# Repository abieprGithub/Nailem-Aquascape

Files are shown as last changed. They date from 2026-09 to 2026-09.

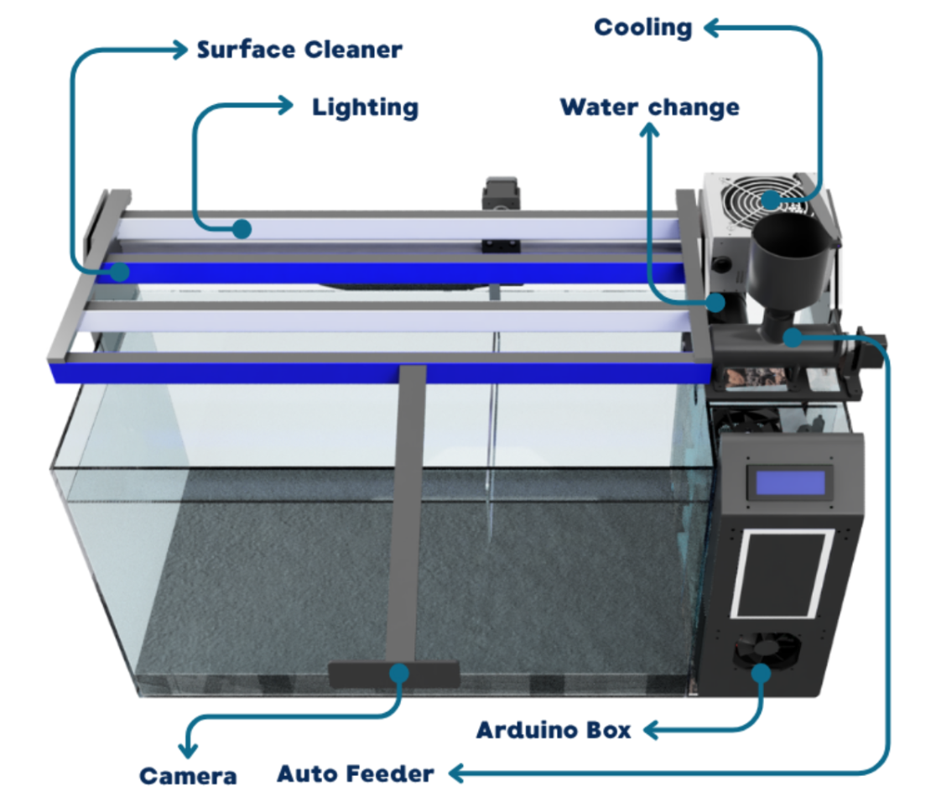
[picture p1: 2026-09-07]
images/diagram.png

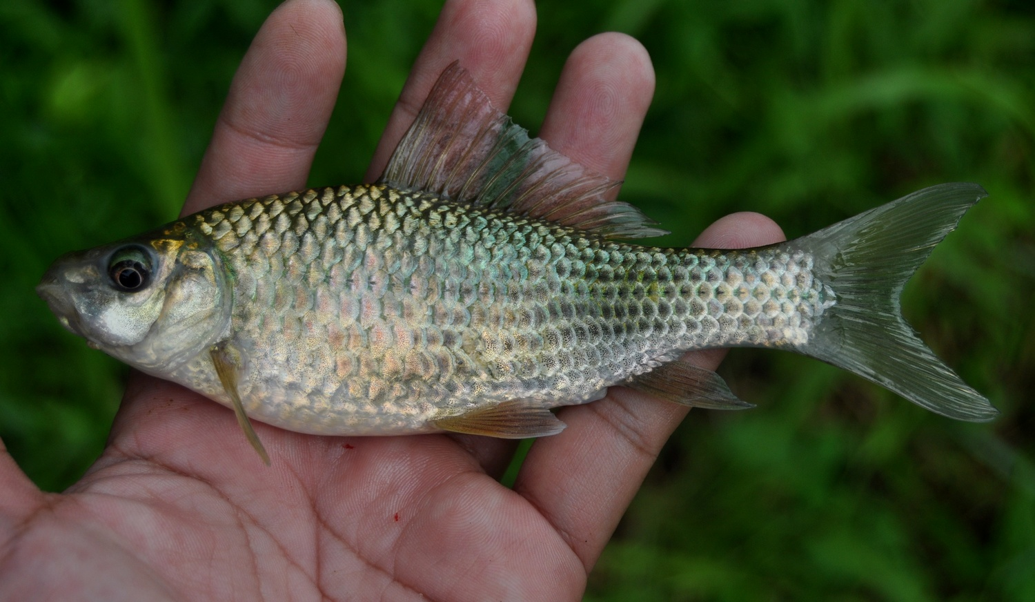
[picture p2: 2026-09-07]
images/nilem.png

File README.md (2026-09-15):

# Nailem: Smart Aquascape
nailemlogolr

As the name suggests, N**ai**lem is an AIoT-powered highly automated aquascape maintenance system, originally designed for Nilem fish (Osteochilus Vittatus):

nilemlr

<br>

🐟 Why Nilem in particular?

1. They're awesome
2. They're tuff (as in they can live in harsh conditions)
3. They're edible (yum)
4. They're common in my nation (Indonesia!)
5. They're reasonably sized (for food fish, at least)

### ❗ But more importantly,
This is **not** limited only to Nilem fish, and it will be designed to be scalable and flexible to meet the living conditions of most other fish, across a wide range of scale.
Of course, community contributions help in adapting this to a wider range of fish, though I haven't given myself time to learn how to manage contributions yet.

I've came up with this to solve a very real problem:
1) Raising food fish is a challenging and long process
2) I'm lazy as hell
3) Urban farming shouldn't be limited to crops, but livestock too

## Quick navigation

[🛠️ Technical Functions](detailed-functions) | [⚠️ Disclaimers](disclaimer) | [📜 Bulletin](bulletin)

(doesn't work yet, my bad)

<br>

## ⚙️ Functions

diagramlr

*Note: The following 3D model is old, and I will make a new one from the ground up soon.*

## 🛠️ Technical
It packs a whole load of functions. At its core, it's split between two subsystems: Real time control & AI compute.
At its core is an ESP32-S3 as a real time controller, which is kind of a perfect fit for this since I ended up utilizing almost its full potential.
To clarify a bit, what I mean by 'AI' before is actually just computer vision.
For that, this can be fitted with pretty much any low power computer that has USB or UART support, preferably SBCs designed for edge AI.
The NVIDIA Jetson Orin or the Rasperry Pi 5 + AI HAT should work well.
The thing is, the real time subsystem can exist as a standalone system, omitting the computer vision features entirely if the budget didn't allow.
However, it's 2026 and IoT alone is getting a little bit outdated.

<br>

wiringdiagram_newlr

<br>

### Detailed functions

*Programming or build hasn't started yet, but this gives you an idea of what I wanted to create.* 

**Primary Automation Features:**
1) 💦 Surface cleaning
2) 🌡️ Temperature Regulation
3) 🥄 Feeding
4) 💡Lighting
5) 🔄 Water Change

**Monitored parameters:**
1) Water Temperature
2) Water pH
3) Water TDS
4) Water Turbidity
5) Ambient temperature
6) Ambient humidity
7) Ambient lighting
8) Power consumption

**IoT features:**
1) Web Dashboard
2) API
3) OTA Firmware Update
4) 

**AI Features:**
1) Fish behavior detection
2) Anomaly detection
3) Egg detection (hopefully 😭)

**Miscellaneous features for the sake of the developer and or the user**
1) Two status ARGB LEDs on the board
2) Header for an external ARGB
3) UART debug header
4) USB-C data-only receptacle
5) Highly modular design, both physically and electrically. 

## Disclaimer
This used to be my 8th grade engineering project. However, after the project officially closes, I was NOT satisfied with how this turned out (it was still under 50% done), so I took over this entire project after ensuring that my team is okay with it. 
With that, kudos to my goated team for their work, even though I was responsible for 80% of the technical work:

<br>

Abie (myself) - Programmer, leader; Akbar - Mechanic; Adzka - Mechanic; <br>
Nabil - Management; Shifa - Scientist; Kirana - Media;

<br>
This did technically start before the Hack Club Stardance YSWS, but the amount of revisions made AFTER it started make this practically a new project tbh.
However, I'm still going to state that this project started before the season anyways.

## Bulletin

*This section is intended to show the latest updates, devlogs, or things you should know, and is updated reguarly!*

### 15th of September 2026

While waiting for the PCB to arrive, I took some time to create the CAD of the Aquascape. <br>
P.S, I haven't pushed the CAD to main since it's a little too large, I'll optimize it. <br>
Currently, it has seen great progress and I have created a few things: <br>
1) The aquarium glass
2) Most of the surface cleaning gantry mechanism, which includes:
3) Stepper motor Bracket
4) Endstops
5) Frame
6) Pulleys
7) Ultrasonic sensor bracket
8) Control box

A lot of things are still yet to be implemented, so let things continue. <br>
Meanwhile, here are some latest pictures.
fa57c02a-535e-4093-b632-b597ec595e62





### 7th of September 2026

The main ESP32-S3 IO PCB iteslf has been completed, and has started its production on JLCPCB. It should arrive at my doorsteps within 10-15 days. Meanwhile, I'll be working on the CAD model of the Aquascape with all the time I had. <br>
It took a total of over 20 hours to make it pretty, both electrically, visually, and functionally, whilst also having the constraints of having to fit inside JLCPCB's economic 2 layer footprint so I don't get taxed by Indonesian customs. <br> <br>

Anyways, here are some 3D model and boardview screenshots!
Screenshot from 2026-09-06 19-20-32
Screenshot from 2026-09-06 19-23-08
<br>
Without components:
Screenshot from 2026-09-06 19-20-54
Screenshot from 2026-09-06 19-22-44

<br><br><br><br><br><br><br><br><br><br><br><br><br><br><br><br><br><br><br>

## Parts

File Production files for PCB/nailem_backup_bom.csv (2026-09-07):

Designator | Footprint | Quantity | Value | LCSC Part #
A1 | Pololu_Breakout-16_15.2x20.3mm | 1 | Pololu_Breakout_A4988
C10 | C_Elec_8x10.2 | 1 | 100uF
C11, C12, C6, C8, C9 | 0805 | 5 | 100nF
C2, C3, C4 | 0805 | 3 | 10uF
C5, C7 | 0805 | 2 | 1uF
D1 | SOT-23-6 | 1 | USBLC6-2SC6
D10, D3, D6, D8 | D_SMA-SMB_Universal_Handsoldering_NoSilk | 4 | 1N4007
D11, D12 | LED_SK6812MINI-E_3.2x2.8mm_P1.5mm_ReverseMount | 2 | SK6812MINI-E
D2, D4, D5, D7, D9 | 0805 | 5 | LED
FB1 | 0805 | 1 | FerriteBead
J1 | USB_C_Receptacle_HRO_TYPE-C-31-M-12 | 1 | USB_OTG
J10 | TerminalBlock_Xinya_XY308-2.54-2P_1x02_P2.54mm_Horizontal_NoTriangle | 1 | LED_CH4
J11 | 2EDGK_5.08_2P_M_NEW | 1 | 12VIN
J12 | JST_XH_B4B-XH-A_1x04_P2.50mm_Vertical | 1 | J_SR04
J13 | JST_XH_B3B-XH-A_1x03_P2.50mm_Vertical | 1 | J_DS18B20_1
J14 | JST_XH_B3B-XH-A_1x03_P2.50mm_Vertical | 1 | J_DS18B20_2
J15 | JST_XH_B3B-XH-A_1x03_P2.50mm_Vertical | 1 | J_DS18B20_3
J16 | JST_XH_B3B-XH-A_1x03_P2.50mm_Vertical | 1 | J_DS18B20_4
J17 | JST_XH_B3B-XH-A_1x03_P2.50mm_Vertical | 1 | J_STATUS
J18 | JST_XH_B3B-XH-A_1x03_P2.50mm_Vertical | 1 | J_SERVO
J19 | JST_XH_B3B-XH-A_1x03_P2.50mm_Vertical | 1 | J_TURBIDITY
J2 | JST_XH_B4B-XH-A_1x04_P2.50mm_Vertical | 1 | J_UART
J20 | 2EDGK_5.08_2P_M_NEW | 1 | 5VIN
J21 | JST_XH_B3B-XH-A_1x03_P2.50mm_Vertical | 1 | J_TDS
J22 | JST_XH_B3B-XH-A_1x03_P2.50mm_Vertical | 1 | J_PH
J23 | JST_XH_B4B-XH-A_1x04_P2.50mm_Vertical | 1 | J_STEPPER
J24 | JST_XH_B4B-XH-A_1x04_P2.50mm_Vertical | 1 | J_5V_LCD
J25 | JST_XH_B4B-XH-A_1x04_P2.50mm_Vertical | 1 | J_5V_NEXTION
J26 | JST_XH_B4B-XH-A_1x04_P2.50mm_Vertical | 1 | J_3V3_LUX
J27 | JST_XH_B3B-XH-A_1x03_P2.50mm_Vertical | 1 | J_SERVO2
J28 | JST_XH_B3B-XH-A_1x03_P2.50mm_Vertical | 1 | J_ENDS
J29 | JST_XH_B2B-XH-A_1x02_P2.50mm_Vertical | 1 | 5VPI
J3 | 2EDGK_5.08_2P_M_NEW | 1 | OUT_CH1
J4 | 2EDGK_5.08_2P_M_NEW | 1 | OUT_CH2
J5 | 2EDGK_5.08_2P_M_NEW | 1 | OUT_CH3
J6 | 2EDGK_5.08_2P_M_NEW | 1 | OUT_CH4
J7 | TerminalBlock_Xinya_XY308-2.54-2P_1x02_P2.54mm_Horizontal_NoTriangle | 1 | LED_CH1
J8 | TerminalBlock_Xinya_XY308-2.54-2P_1x02_P2.54mm_Horizontal_NoTriangle | 1 | LED_CH2
J9 | TerminalBlock_Xinya_XY308-2.54-2P_1x02_P2.54mm_Horizontal_NoTriangle | 1 | LED_CH3
K1, K2, K3, K4 | Relay_SPDT_SANYOU_SRD_Series_Form_C_NoInSilk | 4 | SANYOU_SRD_Form_C
Q1, Q2, Q3, Q4 | SOT-23 | 4 | MMBT2222A
Q5, Q6, Q7, Q8 | SO-8FL_DFN5x6 | 4 | AON6980
R1, R2 | 0805 | 2 | 5.1K
R10, R13, R16, R28, R31, R33, R35, R6 | 0805 | 8 | 1K
R11, R14, R29, R3, R32, R34, R36, R7, R8 | 0805 | 9 | 2K
R12, R15, R5, R9 | 0805 | 4 | 100K
R17, R18 | 0805 | 2 | 33
R19 | 0805 | 1 | 220
R20, R23, R25, R27, R37, R38, R39, R4, R40, R41, R42 | 0805 | 11 | 10K
R21, R22, R24, R26 | 0805 | 4 | 47
R30 | 0805 | 1 | 4.7K
SW1 | SW_SPST_TS-1088-xR020 | 1 | SW_RST
SW2 | SW_SPST_TS-1088-xR020 | 1 | SW_BOOT
SW3 | SW_DIP_SPSTx03_Slide_9.78x9.8mm_W7.62mm_P2.54mm | 1 | SW_DIP_x03
U1 | ESP32-S3-WROOM-1U | 1 | ESP32-S3-WROOM-1
U2 | SOT-223-3_TabPin2 | 1 | AMS1117-3.3
U3 | INA3221_Module_P2.54mm_NoVPU_NoExtraGnds | 1 | INA3221_Module

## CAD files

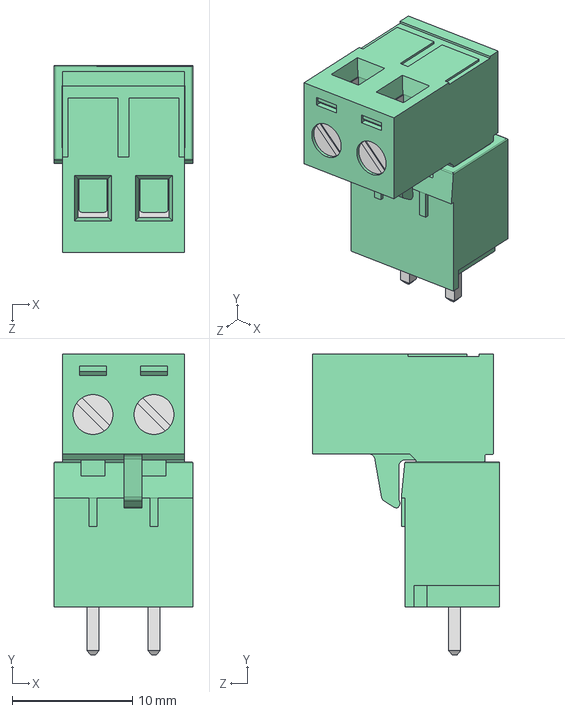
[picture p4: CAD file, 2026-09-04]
Nailem-Main-PCB/2EDG-5.08-02P.STEP
11.6 x 25.1 x 15.6 mm
2EDGVC-5.08-02P
2EGDK-5.08-02P

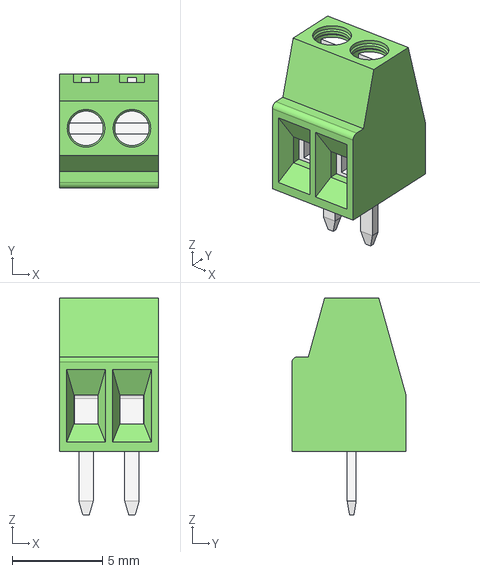
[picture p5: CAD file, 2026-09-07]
Nailem-Main-PCB/3D_Models/KF128-2.54-2P.step
5.48 x 6.30 x 12.0 mm
Connector_body

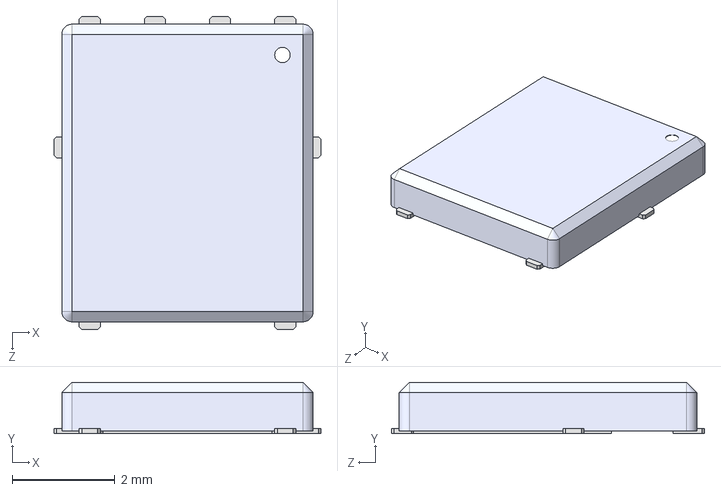
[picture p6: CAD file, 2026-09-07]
Nailem-Main-PCB/3D_Models/SO-8FL.STEP
5.20 x 1.00 x 6.10 mm

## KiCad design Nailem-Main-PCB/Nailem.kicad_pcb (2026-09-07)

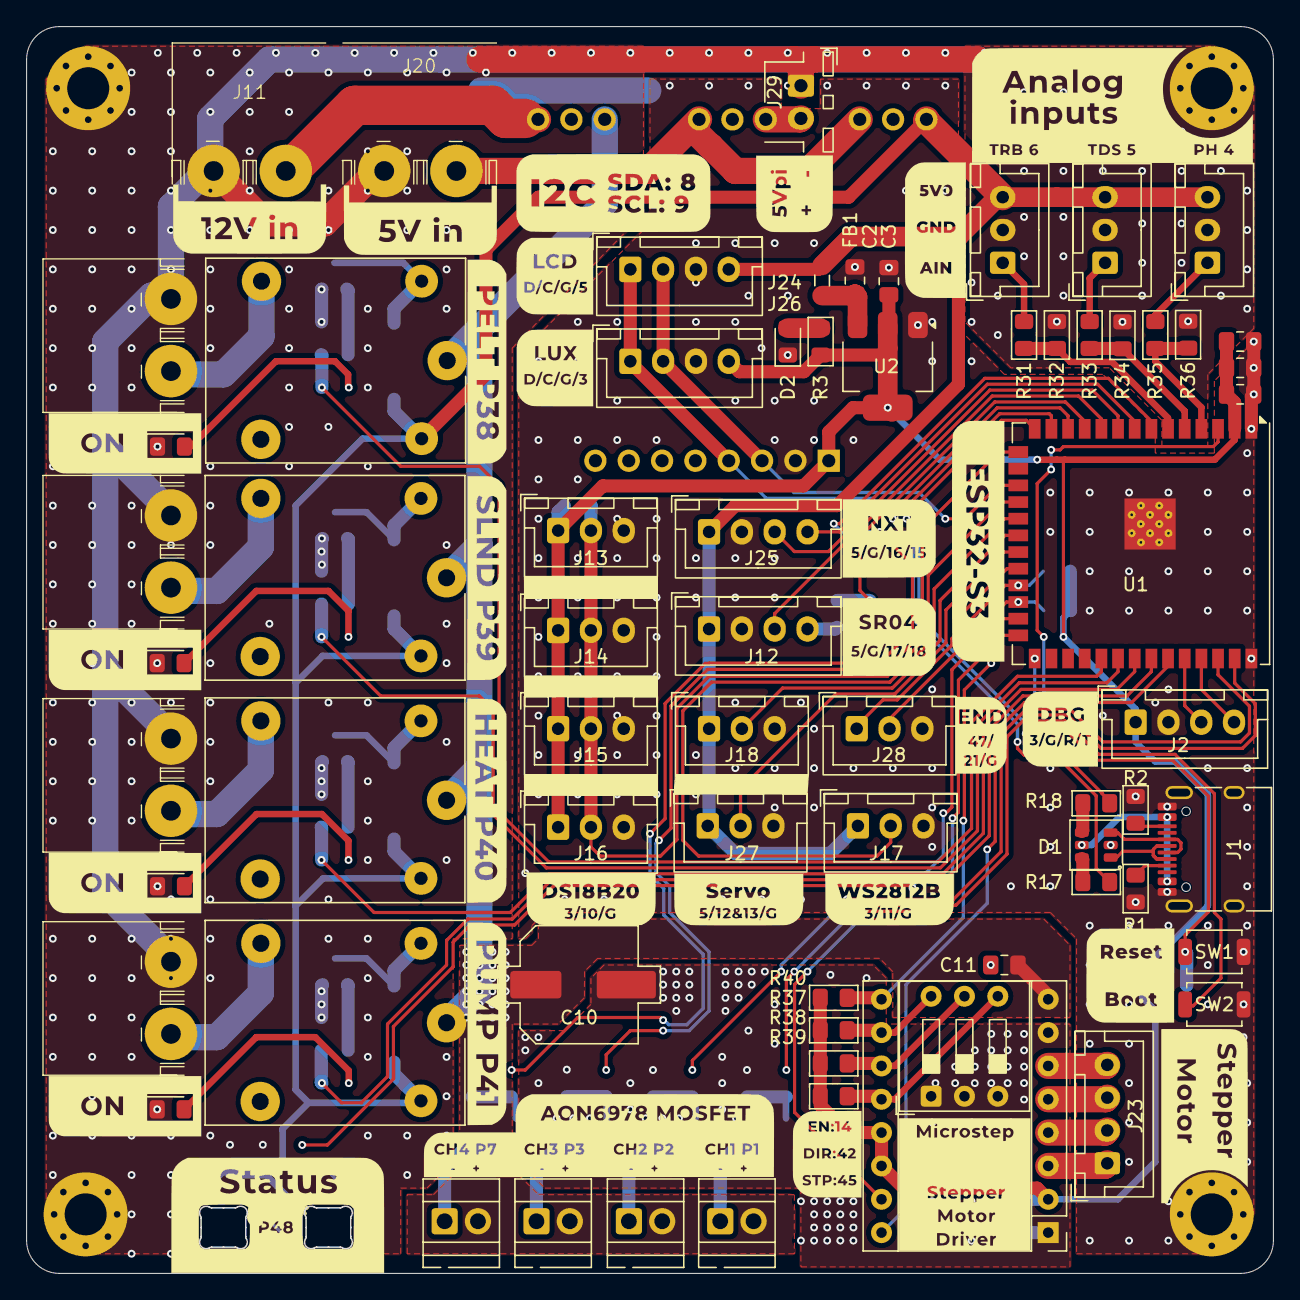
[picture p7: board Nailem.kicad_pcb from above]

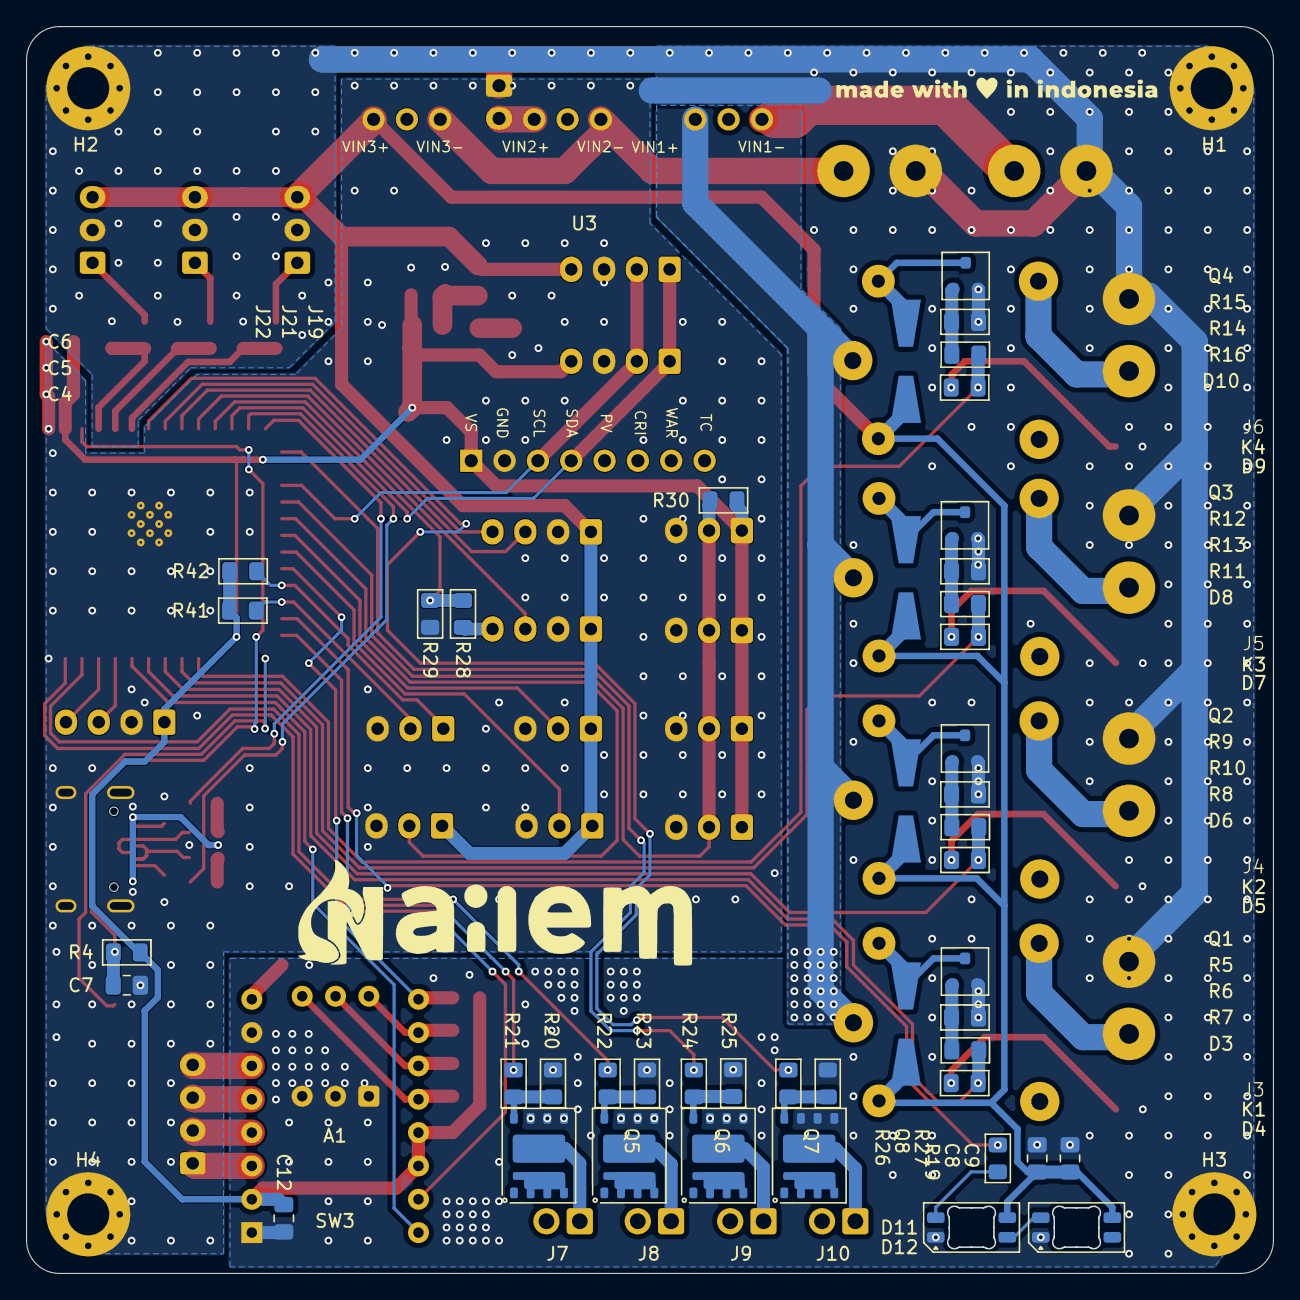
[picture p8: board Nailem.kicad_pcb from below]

Board: 2 copper layers, 95.0 x 95.0 mm, 118 parts (46 on the bottom side), 86 nets.

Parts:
A1: Pololu_Breakout_A4988; Pololu_Breakout-16_15.2x20.3mm
C2, C3, C4: 10uF; C_0805_2012Metric_Pad1.18x1.45mm_HandSolder
C5, C7: 1uF; C_0805_2012Metric_Pad1.18x1.45mm_HandSolder
C6, C8, C9, C11, C12: 100nF; C_0805_2012Metric_Pad1.18x1.45mm_HandSolder
C10: 100uF; C_Elec_8x10.2
D1: USBLC6-2SC6; SOT-23-6
D2, D4, D5, D7, D9: LED; LED_0805_2012Metric_Pad1.15x1.40mm_HandSolder
D3, D6, D8, D10: 1N4007; D_SMA-SMB_Universal_Handsoldering_NoSilk
D11, D12: SK6812MINI-E; LED_SK6812MINI-E_3.2x2.8mm_P1.5mm_ReverseMount
FB1: FerriteBead; L_0805_2012Metric_Pad1.05x1.20mm_HandSolder
H1, H2, H3, H4: MountingHole; MountingHole_3.2mm_M3_Pad_Via
J1: USB_OTG; USB_C_Receptacle_HRO_TYPE-C-31-M-12
J2: J_UART; JST_XH_B4B-XH-A_1x04_P2.50mm_Vertical
J3: OUT_CH1; 2EDGK_5.08_2P_M_NEW
J4: OUT_CH2; 2EDGK_5.08_2P_M_NEW
J5: OUT_CH3; 2EDGK_5.08_2P_M_NEW
J6: OUT_CH4; 2EDGK_5.08_2P_M_NEW
J7: LED_CH1; TerminalBlock_Xinya_XY308-2.54-2P_1x02_P2.54mm_Horizontal_N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
J8: LED_CH2; TerminalBlock_Xinya_XY308-2.54-2P_1x02_P2.54mm_Horizontal_N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
J9: LED_CH3; TerminalBlock_Xinya_XY308-2.54-2P_1x02_P2.54mm_Horizontal_N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
J10: LED_CH4; TerminalBlock_Xinya_XY308-2.54-2P_1x02_P2.54mm_Horizontal_N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
J11: 12VIN; 2EDGK_5.08_2P_M_NEW
J12: J_SR04; JST_XH_B4B-XH-A_1x04_P2.50mm_Vertical
J13: J_DS18B20_1; JST_XH_B3B-XH-A_1x03_P2.50mm_Vertical
J14: J_DS18B20_2; JST_XH_B3B-XH-A_1x03_P2.50mm_Vertical
J15: J_DS18B20_3; JST_XH_B3B-XH-A_1x03_P2.50mm_Vertical
J16: J_DS18B20_4; JST_XH_B3B-XH-A_1x03_P2.50mm_Vertical
J17: J_STATUS; JST_XH_B3B-XH-A_1x03_P2.50mm_Vertical
J18: J_SERVO; JST_XH_B3B-XH-A_1x03_P2.50mm_Vertical
J19: J_TURBIDITY; JST_XH_B3B-XH-A_1x03_P2.50mm_Vertical
J20: 5VIN; 2EDGK_5.08_2P_M_NEW
J21: J_TDS; JST_XH_B3B-XH-A_1x03_P2.50mm_Vertical
J22: J_PH; JST_XH_B3B-XH-A_1x03_P2.50mm_Vertical
J23: J_STEPPER; JST_XH_B4B-XH-A_1x04_P2.50mm_Vertical
J24: J_5V_LCD; JST_XH_B4B-XH-A_1x04_P2.50mm_Vertical
J25: J_5V_NEXTION; JST_XH_B4B-XH-A_1x04_P2.50mm_Vertical
J26: J_3V3_LUX; JST_XH_B4B-XH-A_1x04_P2.50mm_Vertical
J27: J_SERVO2; JST_XH_B3B-XH-A_1x03_P2.50mm_Vertical
J28: J_ENDS; JST_XH_B3B-XH-A_1x03_P2.50mm_Vertical
J29: 5VPI; JST_XH_B2B-XH-A_1x02_P2.50mm_Vertical
K1, K2, K3, K4: SANYOU_SRD_Form_C; Relay_SPDT_SANYOU_SRD_Series_Form_C_NoInSilk
Q1, Q2, Q3, Q4: MMBT2222A; SOT-23
Q5, Q6, Q7, Q8: AON6980; SO-8FL_DFN5x6
R1, R2: 5.1K; R_0805_2012Metric_Pad1.15x1.40mm_HandSolder
R3, R7, R8, R11, R14, R29, R32, R34, R36: 2K; R_0805_2012Metric_Pad1.15x1.40mm_HandSolder
R4, R20, R23, R25, R27, R37, R38, R39, R40, R41, R42: 10K; R_0805_2012Metric_Pad1.15x1.40mm_HandSolder
R5, R9, R12, R15: 100K; R_0805_2012Metric_Pad1.15x1.40mm_HandSolder
R6, R10, R13, R16, R28, R31, R33, R35: 1K; R_0805_2012Metric_Pad1.15x1.40mm_HandSolder
R17, R18: 33; R_0805_2012Metric_Pad1.15x1.40mm_HandSolder
R19: 220; R_0805_2012Metric_Pad1.15x1.40mm_HandSolder
R21, R22, R24, R26: 47; R_0805_2012Metric_Pad1.15x1.40mm_HandSolder
R30: 4.7K; R_0805_2012Metric_Pad1.15x1.40mm_HandSolder
SW1: SW_RST; SW_SPST_TS-1088-xR020
SW2: SW_BOOT; SW_SPST_TS-1088-xR020
SW3: SW_DIP_x03; SW_DIP_SPSTx03_Slide_9.78x9.8mm_W7.62mm_P2.54mm
U1: ESP32-S3-WROOM-1; ESP32-S3-WROOM-1U
U2: AMS1117-3.3; SOT-223-3_TabPin2
U3: INA3221_Module; INA3221_Module_P2.54mm_NoVPU_NoExtraGnds

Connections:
3V3LOGIC: A1.2 (VDD), A1.13 (~RESET), A1.14 (~SLEEP), C3.1, C4.1, C5.1, C6.1, C12.1, J2.1, J13.1, J14.1, J15.1, J16.1, J26.4, R3.2, R4.1, R30.1, R37.2, R38.2, R39.2, R40.2, R41.1, R42.1, U1.2 (3V3), U2.2 (VO), U3.1 (VS)
5VIN: C8.1, C9.1, D3.1 (K), D6.1 (K), D8.1 (K), D10.1 (K), D11.3 (VDD), D12.3 (VDD), FB1.1, J12.1, J17.1, J18.1, J19.3, J21.3, J22.3, J24.4, J25.1, J27.1, K1.5, K2.5, K3.5, K4.5, U3.14 (VIN3+)
5VPI: J29.2, U3.12 (VIN2+)
12V: A1.8 (VMOT), C10.1, C11.1, J7.2, J8.2, J9.2, J10.2, K1.1, K2.1, K3.1, K4.1, U3.10 (VIN1+)
CUR_N_CH1: J11.2, U3.9 (VIN1-)
CUR_N_CH2: J20.2, U3.11 (VIN2-), U3.13 (VIN3-)
DS18B20_BUS: J13.2, J14.2, J15.2, J16.2, R30.2, U1.18 (IO10)
END_XMIN: J28.1, R42.2, U1.23 (IO21)
END_XPLUS: J28.2, R41.2, U1.24 (IO47)
ESP_RX: J2.3, U1.36 (RXD0)
ESP_TX: J2.4, U1.37 (TXD0)
GND: A1.1 (GND), A1.7 (GND), C2.2, C3.2, C4.2, C5.2, C6.2, C7.2, C8.2, C9.2, C10.2, C11.2, C12.2, D1.2 (VN), D2.1 (K), D4.1 (K), D5.1 (K), D7.1 (K), D9.1 (K), D11.1 (VSS), D12.1 (VSS), H1.1 (1_1), H2.1 (1_1), H3.1 (1_1), H4.1 (1_1), J1.A1 (GND), J1.A12 (GND), J1.B1 (GND), J1.B12 (GND), J1.SH (SHIELD), J2.2, J3.2, J4.2, J5.2, J6.2, J11.1, J12.2, J13.3, J14.3, J15.3, J16.3, J17.3, J18.3, J19.2, J20.1, J21.2, J22.2, J24.3, J25.2, J26.3, J27.3, J28.3, J29.1, Q1.2 (E), Q2.2 (E), Q3.2 (E), Q4.2 (E), Q5.3 (S2), Q5.4 (S2), Q5.5 (S2), Q6.3 (S2), Q6.4 (S2), Q6.5 (S2), Q7.3 (S2), Q7.4 (S2), Q7.5 (S2), Q8.3 (S2), Q8.4 (S2), Q8.5 (S2), R1.1, R2.1, R5.1, R9.1, R12.1, R15.1, R20.2, R23.2, R25.2, R27.2, R29.1, R32.1, R34.1, R36.1, SW1.1 (A), SW2.1 (A), SW3.1, SW3.2, SW3.3, U1.1 (GND), U1.40 (GND), U1.41 (GND), U2.1 (GND), U3.2 (GND)
HCSR04_ECHO: R28.2, R29.2, U1.11 (IO18)
HCSR04_TRIG: J12.3, U1.10 (IO17)
I2C_SCL: J24.2, J26.2, U1.17 (IO9), U3.3 (SCL)
I2C_SDA: J24.1, J26.1, U1.12 (IO8), U3.4 (SDA)
IND_ARGB: R19.1, U1.25 (IO48)
LED_DRV_CH1: R21.1, U1.39 (IO1)
LED_DRV_CH2: R22.1, U1.38 (IO2)
LED_DRV_CH3: R24.1, U1.15 (IO3)
LED_DRV_CH4: R26.1, U1.7 (IO7)
NX_RX: J25.3, U1.9 (IO16)
NX_TX: J25.4, U1.8 (IO15)
unnamed: A1.4 (1A), J23.2
unnamed: A1.3 (1B), J23.1
unnamed: A1.5 (2A), J23.3
unnamed: A1.6 (2B), J23.4
unnamed: A1.10 (MS1), R37.1, SW3.6
unnamed: A1.11 (MS2), R38.1, SW3.5
unnamed: A1.12 (MS3), R39.1, SW3.4
unnamed: D1.1 (L1), J1.A7 (D-), J1.B7 (D-)
unnamed: D1.3 (L2), J1.A6 (D+), J1.B6 (D+)
unnamed: D1.5 (VP), J1.A4 (VBUS), J1.A9 (VBUS), J1.B4 (VBUS), J1.B9 (VBUS)
unnamed: D2.2 (A), R3.1
unnamed: D3.2 (A), K1.2, Q1.3 (C)
unnamed: D4.2 (A), R7.1
unnamed: D5.2 (A), R8.1
unnamed: D6.2 (A), K2.2, Q2.3 (C)
unnamed: D7.2 (A), R11.1
unnamed: D8.2 (A), K3.2, Q3.3 (C)
unnamed: D9.2 (A), R14.1
unnamed: D10.2 (A), K4.2, Q4.3 (C)
unnamed: D11.2 (DIN), R19.2
unnamed: D11.4 (DOUT), D12.2 (DIN)
unnamed: J1.A5 (CC1), R1.2
unnamed: J1.B5 (CC2), R2.2
unnamed: J3.1, K1.3
unnamed: J4.1, K2.3
unnamed: J5.1, K3.3
unnamed: J6.1, K4.3
unnamed: J7.1, Q5.7 (C)
unnamed: J8.1, Q6.7 (C)
unnamed: J9.1, Q7.7 (C)
unnamed: J10.1, Q8.7 (C)
unnamed: J12.4, R28.1
unnamed: J19.1, R31.2
unnamed: J21.1, R33.2
unnamed: J22.1, R35.2
unnamed: Q1.1 (B), R5.2, R6.2
unnamed: Q2.1 (B), R9.2, R10.2
unnamed: Q3.1 (B), R12.2, R13.2
unnamed: Q4.1 (B), R15.2, R16.2
unnamed: Q5.6 (G2), R20.1, R21.2
unnamed: Q6.6 (G2), R22.2, R23.1
unnamed: Q7.6 (G2), R24.2, R25.1
unnamed: Q8.6 (G2), R26.2, R27.1
unnamed: C7.1, R4.2, SW1.2 (B), U1.3 (EN)
unnamed: SW2.2 (B), U1.27 (IO0)
unnamed: R18.2, U1.14 (USB_D+)
unnamed: R17.2, U1.13 (USB_D-)
unnamed: C2.1, FB1.2, U2.3 (VI)
OTG_DN: D1.6 (L1), R17.1
OTG_DP: D1.4 (L2), R18.1
PH_Ain: R35.1, R36.2, U1.4 (IO4)
RELAY_CH1: R6.1, R7.2, U1.34 (IO41)
RELAY_CH2: R8.2, R10.1, U1.33 (IO40)
RELAY_CH3: R11.2, R13.1, U1.32 (IO39)
RELAY_CH4: R14.2, R16.1, U1.31 (IO38)
SERVO2_PWM: J27.2, U1.21 (IO13)
SERVO_PWM: J18.2, U1.20 (IO12)
STEP_DIR: A1.16 (DIR), U1.35 (IO42)
STEP_EN: A1.9 (~ENABLE), R40.1, U1.22 (IO14)
STEP_STP: A1.15 (STEP), U1.26 (IO45)
TDS_Ain: R33.1, R34.2, U1.5 (IO5)
TURB_Ain: R31.1, R32.2, U1.6 (IO6)
WS2812_BUS: J17.2, U1.19 (IO11)

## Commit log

2026-09-04 Add existing local files
    Upload current existing progress to the main branch
    [2EDG-5.08-02P.STEP, Nailem.kicad_pcb, Nailem.kicad_sch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]
2026-09-04 Organize file structure
    Add folder: misc, images
    Move: PCB > Nailem-Main-PCB
    [2EDG-5.08-02P.STEP, Nailem.kicad_pcb, Nailem.kicad_sch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]
2026-09-05 Update README
    Add wiring diagram
    Fix typos
    Minor visual changes
2026-09-07 Finalize PCB
    PCB complete, and is currently being produced under JLCPCB with files in 'Production files for PCB'
    [KF128-2.54-2P.step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]
2026-09-07 Organize CAD directory
    Nailem.step moved to root/CAD
2026-09-07 Update README Bulletin
    About the PCB being finished
